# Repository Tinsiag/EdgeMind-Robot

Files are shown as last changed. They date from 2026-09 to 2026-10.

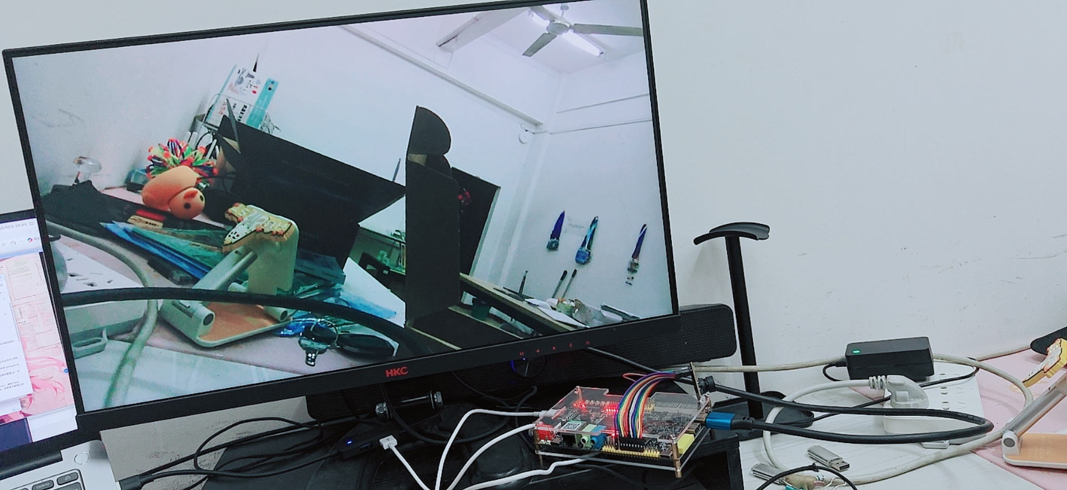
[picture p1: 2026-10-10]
code/fpga/acg720-ddr3/verification/verified-20261008/hardware-evidence/hdmi_scene.png

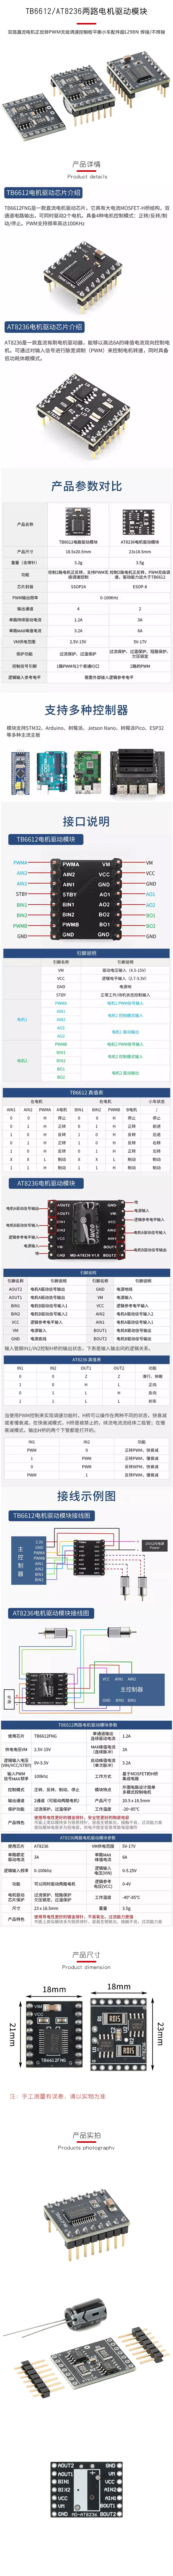
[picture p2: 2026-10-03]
doc/电机/合并长图_1-9.png

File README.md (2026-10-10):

# EdgeMind-Robot

基于 ACG720 FPGA 的双轮差速自主移动机器人项目。目标是先完成轮速闭环、传感器感知、视频链路与安全保护，再按需要扩展 Lichee Pi 4A 视觉计算。

## 文档与设计

- [项目功能需求书](doc/项目功能需求书.md)
- [系统设计文档](doc/文档.md)
- [电源预算与电源板架构初稿](doc/电源板/电源预算与架构初稿.md)
- [拟用电机资料核对](doc/电机/拟用电机资料核对.md)
- [FPGA 资料索引](doc/fpga/README.md)
- [代码目录](code/README.md)（含 ACG720 摄像头、DDR3 和电机工程入口与联调记录）
- [OV5640 与 DDR3 帧缓存排查及实现](code/fpga/acg720-ddr3/DDR3-FRAMEBUFFER-IMPLEMENTATION-2026-10-08.md)（800×480 静态、彩条、实景单帧链路通过）
- [DDR3 实景 HDMI 固件与验证资料](code/fpga/acg720-ddr3/verification/verified-20261008/README.md)（导入位流、实景显示反馈、照片与构建报告；完整时序尚未闭合）
- [机械参考图](model/README.md)（仅供版型与尺寸初查）
- [KiCad 电源板工程](pcb/power/)

当前电源预算和 KiCad 工程均为设计阶段内容，不代表电路已完成验证。板卡、电机、驱动、电池以及模块的供电范围和实际电流须按实物复核。

公开仓库收录项目文档、可编辑设计文件，以及 `model/` 下已有的两张机械参考图。WHEELTEC、ACG720 等厂家随附的原始 PDF、CAD 模型、安装包、视频与示例工程保留在本地；尤其 WHEELTEC 资料包的版权声明限制未经许可传播，故未上传这些原始附件。需要原始资料时请从厂家或购买渠道获取。

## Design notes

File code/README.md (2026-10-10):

# 代码目录

- [ACG720 / AT8236 电机控制](fpga/acg720-motor-test/README.md)：A712 启动和编码器活动、A713 左右持续启停已实测通过；当前 A717 为 50 kHz，占空比从 0% 到 100% 每 0.5 秒增加 5% 后循环，已下载，实物表现待反馈。S1/S2 独立启停，S0 停止，仅操作 SRAM。
- [电机启动排查与实现文档](fpga/acg720-motor-test/MOTOR-IMPLEMENTATION-2026-10-10.md)：接线、电源、三个 PWM 对照版本、通过证据及复现方法；尚未实现速度 PID 或与摄像头合并。
- [ACG720 GW5AT-60 DDR3 验证工程](fpga/acg720-ddr3/README.md)：原有 800×480 静态、彩条、实景单帧验证均通过。另已合入 [实景 HDMI 交付包](fpga/acg720-ddr3/verification/verified-20261008/README.md)，包含位流、实物反馈与完整验证资料；有图像显示反馈，时序尚未闭合，包内未提供完整 RTL。许可证已解决。
- [DDR3 帧缓存排查与实现文档](fpga/acg720-ddr3/DDR3-FRAMEBUFFER-IMPLEMENTATION-2026-10-08.md)：旧诊断缺陷、时钟与缓存实现、摄像头配置、仿真/实板证据、复现步骤和断电保存边界。

原厂配套源码、加密 IP 和位流保留在工程的 `.local/` 中，不直接并入公开仓库。我们编写的说明和构建入口纳入版本管理。

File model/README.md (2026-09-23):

# 机械参考图

本目录当前包含两张用户保存的板卡机械参考图，并非可编辑的 STEP/DWG 模型，也不能替代实物测量。

- `BE11300D28AD57C96EC11B6DEDBB3751.bmp`：灰度板卡布局图，图中标注外形约 84.45 mm × 99.06 mm；具体板型尚未核实。
- `EDE6B28DC4BC051CA18BC4B2684486C0.png`：Autodesk Viewer 的 `ACX720-V3.DWG.png` 截图，图中标注约 132.46 mm × 85.98 mm。

两张图的尺寸不同，不能把它们当成同一板卡的正反面或直接套用到 ACG720。开孔、接口和板框须对照实物及对应版本的正式机械图复核。原始设计文件的权利仍归相应提供方所有。

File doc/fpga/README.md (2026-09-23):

# FPGA 资料索引

本目录从 `/home/smallcoral/Dev/fpga/ACG720` 中筛选而来，只保留与 EdgeMind-Robot 当前方案直接相关的开发文档、硬件资料和机械模型。

**公开仓库说明：**本地目录保留原厂 PDF、表格和机械模型，GitHub 仓库仅收录我们撰写的 Markdown 索引与核对记录。下文指向原厂附件的相对路径需要在本地资料包中打开；若从 GitHub 克隆，需从厂家或购买渠道获取原始资料，不应将这些附件重新公开分发。

整理日期：2026-09-23。

## 目录说明

| 目录 | 内容 | 建议用途 |
| --- | --- | --- |
| `00_资料索引` | 原资料包的整理报告、章节导航、硬件与引脚核对、原始引脚表 | 开始开发前先读，了解资料冲突与已知问题 |
| `01_板卡硬件` | ACG720 主板原理图、通用引脚表、机械资料外链 | 接线、供电、IO Bank 电压和约束核对 |
| `02_官方开发手册` | Gowin 中文官方手册、Arora V 资源手册、Programmer 手册、PicoRV32 IP 配置说明 | 工具、约束、时序、GPIO、时钟、存储器、DSP 与软核开发 |
| `03_相关教程` | 从 70 章教程中筛出的 26 章 PDF | UART、状态机、IP、PWM、TFT/HDMI、I2C、DDR3、OV5640 |
| `04_机械模型` | ACX720 V2/V3 的 DWG、PcbDoc、STEP、STL、GLB、DXF、SVG 等参考模型 | 结构设计和安装空间预估；必须与 ACG720 实物复核 |
| `05_OV5640摄像头` | ACM5640-V5 用户指南、原理图、丝印、OV5640/SCCB/DVP 资料 | 摄像头接线、SCCB 初始化和 DVP 采集 |
| `06_显示屏` | 4.3/5 寸 TFT 背板、屏体、触控芯片和连接器资料 | 确认最终屏幕型号后选择性使用 |
| `07_关键器件数据` | 板载 DDR3、DVI、CH340、EEPROM、缓冲器手册 | DDR 视频缓存与板级接口排查 |
| `08_电机与驱动` | 现有 FPGA 双电机 PID 文档和 BTS7960/IBT-2 资料；拟用两种电机资料核对位于 `doc/电机/` | 核对驱动选型与现有控制实现 |

## 推荐阅读顺序

1. `00_资料索引/硬件与引脚核对.md`
2. `01_板卡硬件/ACG720_138K-60K通用原理图.pdf`
3. `01_板卡硬件/ACG720_138K-60K通用引脚分配.xlsx`
4. `02_官方开发手册/SUG100-4.4.6_Gowin云源软件用户指南.pdf`
5. `03_相关教程/02_Gowin基本开发流程.pdf`
6. 根据当前里程碑阅读 UART、PWM、I2C、DDR3、OV5640 或显示章节。

## 重要注意事项

- ACG720 资料同时涉及 GW5AT-138K 和 GW5AT-60K，工程器件、完整料号、引脚与配置手册必须按实物板卡选择。
- `04_机械模型` 的原始目录名为 `ACX720-V3机械文件`，不能直接认定其尺寸与 ACG720 完全一致；开孔、连接器位置和板框必须按实物或正式机械图复核。
- 原 ACG720 资料包没有独立的 MG513X/MG513XP28 电机数据手册，也没有 DRV8874 数据手册。现已在本地 `doc/电机/WHEELTEC 直流电机附送资料` 找到 WHEELTEC 的 MG513X 手册，可确认 1:28、12 V、0.36 A 额定、3.2 A 堵转等系列参数；实物编码器版本和实际电流仍需核对。两种拟用电机的铭牌与接线记录见 `doc/电机/拟用电机资料核对.md`。原厂手册不随公开仓库上传。
- `08_电机与驱动` 中的旧 PID 工程面向 TB6612；BTS7960/IBT-2 也是来源目录中的备选资料。当前项目计划优先评估 DRV8874，这些资料只能作为参考，不能替代最终驱动选型验证。
- 摄像头 V5 资料对自动对焦和补光能力存在版本描述冲突，应以手头模块实物、原理图和测试结果为准。
- 教程 PDF 中的示例参数、CST 和器件选择不一定都适用于当前板型，移植时应重新核对时钟、复位、IO 电压和时序约束。

## 未复制的内容

- `02_code` 示例工程与 RTL 源码
- `03_videos` 课程视频及随视频附带的工程输出
- `05_sofeware` 软件安装程序、工具运行文件和重复语言手册
- 仿真目录、综合/P&R 输出、位流、日志和版本管理残留
- 与机器人当前功能无直接关系的以太网、USB2.0、音频、红外、ADC/DAC 等整套教学资料

如需示例代码或某个未归档的器件手册，仍可从原始 ACG720 目录按需取用，不建议把整个资源包纳入本项目仓库。

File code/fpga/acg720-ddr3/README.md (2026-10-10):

# ACG720 GW5AT-60 DDR3 验证工程

本目录保存 ACG720 / GW5AT-60B 的 DDR3 调试工程。2026-10-08 本机已按官方第 38 章基线打通 OV5640 → 写 FIFO → DDR3 → 读 FIFO，800×480 RGB565 静态、彩条、实景整帧验证均通过。原有工程为实景单帧自检，只有 SRAM 配置，不断电保存；该阶段未验证连续 HDMI 显示。第 47 章 1280×720 主工程保留作历史。原厂依赖及本机构建产物保存在被 Git 忽略的 .local/ 下；原始资料包保持不变。

2026-10-10 另合入用户提供的 [DDR3 实景 HDMI 交付包](verification/verified-20261008/README.md)，完整保存 30 个原始文件，包含 `0x0000BC6C` 位流、HDMI 实景照片、用户反馈、构建/仿真及 PNR 报告。该包有实景显示功能反馈，完整时序仍有 101 个 setup、29 个 hold 违反端点；镜头移动后的刷新及长时间稳定性未单独确认，包内没有完整 RTL 源码。它与下述单帧自检工程和历史结果分开归档。

完整排查、实现与复现文档：[DDR3-FRAMEBUFFER-IMPLEMENTATION-2026-10-08.md](DDR3-FRAMEBUFFER-IMPLEMENTATION-2026-10-08.md)。

仓库也保存 [工程重建脚本](scripts/README.md)、`rtl/camera_init/` 中自编 SCCB 源码和 [实板验证快照](verification/README.md)。原厂依赖按脚本说明放入本机 `.local` 后，可重建本次三个工作工程。

历史交接记录：[DEBUG-HANDOFF-2026-10-06.md](DEBUG-HANDOFF-2026-10-06.md)。10 月 7 日已按用户要求继续，最新过程见 [DEBUG-SESSION-2026-10-07.md](DEBUG-SESSION-2026-10-07.md)。

2026-10-08 用户调整方向：先以官方第 38 章帧缓冲为基线，再向上接入 TY-OV5640。源码、硬件、电平和逻辑分析仪核对结果见 [FRAMEBUFFER-FIRST-PLAN-2026-10-08.md](FRAMEBUFFER-FIRST-PLAN-2026-10-08.md)。随后完成静态整帧验证，用户确认 `0x41A4` 的 D0～D5 亮、D6 灭、D7 闪：384000 像素 / 768000 字节经两端 FIFO 和 DDR 逐像素一致。详见 [FRAMEBUFFER-TEST-RESULT-2026-10-08.md](FRAMEBUFFER-TEST-RESULT-2026-10-08.md)。官方参考副本保持不变，摄像头彩条测试在独立工程继续。

2026-10-08 接线位置图及采集步骤见 [LOGIC-ANALYZER-WIRING-2026-10-08.md](LOGIC-ANALYZER-WIRING-2026-10-08.md)。P7 正面左下为 1 脚方形焊盘，外排偶数、内排奇数；模块 PWDN 在模块侧采集。本次仅整理接线图，没有编译、下载、实物接线或采集。

## 本机单帧验证历史状态（2026-10-08）

| 验证层级 | 已取得的证据 | 结论 |
| --- | --- | --- |
| 本机编译 | 主工程、固定模式 BIST、摄像头 DDR 诊断完成综合、布局布线和位流生成 | 已通过编译流程；尚未完整时序签核 |
| SRAM 下载 | Gowin USB Cable(FT2CH)，FPGA ID 0x0001481B，下载 100% 完成 | 下载成功；未写外部 Flash |
| DDR3 校准 | 10 月 8 日第 38 章整帧版 `0x41A4`，D0/D1/D2 亮 | 新帧缓存基线通过 |
| DDR3 静态整帧读回 | `0x41A4` D3/D4/D5 亮、D6 灭，48000 个读写命令，384000 个像素逐个比较 | 768000 字节链路通过；原 BIST 256 字节通过也保留 |
| 摄像头初始化 | 原主工程复核通过；被动观测版 D2/D4/D5 亮 | 初始化通过，DVP 像素及写 FIFO 输入已有活动 |
| 摄像头像素经 DDR 读回 | 彩条 `0x4FCF`、实景 `0xAF89` 均由用户确认 D0～D5 亮、D6 灭、D7 闪，完整帧 CRC 一致 | 摄像头完整帧链路通过；旧校准失败唯一触发未确定 |
| HDMI 图像 | 没有连接显示器 | 未验证 |

**2026-10-08 本机下载并验证了实景单帧版 `0xAF89`，用户确认 D0～D5 亮、D6 灭、D7 闪；彩条 `0x4FCF` 和静态 `0x41A4` 也已通过。三版均仅 SRAM 下载，外部配置 Flash 未写，断电会丢失配置。** 摄像头版位流、哈希、灯态定义、仿真和时序限制见 [CAMERA-FRAME-TEST-2026-10-08.md](CAMERA-FRAME-TEST-2026-10-08.md)。历史快照不表示当前板上配置；最近一次本机下载见 [电机工程 A717](../acg720-motor-test/README.md)。

- 已通过位流：.local/framebuffer-first/ch38-frame-test/impl/pnr/ch38_frame_test.fs
- SHA256：DD7959D0C266BD507D50DE8FBCF6DE9F9487E5F3B2076F643A168929D81A6222
- User Code / Status：0x000041A4 / 0x70026020
- 本版 D0～D5 均亮、D6 灭、D7 闪；含义与旧摄像头诊断不同，详见整帧验证记录。
- 前一观测版 0x7E20：用户确认 D1 灭，D0/D2/D3/D4/D5 亮。增加探针未解决校准。
- 仅 SRAM 下载，未写 Flash；断电会丢失本次配置。

已定位到源码连接缺陷：`pll_init_bypass=0` 使 DDR 的 mDRP 控制被屏蔽，适配器被综合删除。新帧缓存基线按原厂更新说明，在 PLL 锁定延迟后交出 mDRP 控制权，综合后适配器已保留，实板校准及静态整帧读回已通过。尚未单独做 A/B 测试，不能将旧诊断失败全部归因于这一处。原主工程和已通过 BIST 的位流及源码保持不变。

不能把该诊断版本的 D1 灭直接解释为 DDR 硬件故障。主工程与独立 BIST 曾通过校准，固定模式 BIST 也完成了真实写入/读回；失败诊断的根因仍待定位。

10 月 8 日进一步确认旧 FIFO 诊断存在写入数据量不足（2 个块却要求 8 个块才写）、未等实际写入完成就读、FWFT 比较晚一拍等缺陷；这些发生在校准之后，不能解释当时 D1 灭。证据及限制见 [LEGACY-DDR-DIAGNOSIS-2026-10-08.md](LEGACY-DDR-DIAGNOSIS-2026-10-08.md)。

## 本地工程与工具

| 文件 | 用途 |
| --- | --- |
| .local/framebuffer-first/ch38-frame-test/ch38_frame_test.gprj、build_ch38_frame_test.tcl | 已通过 800×480 静态整帧 DDR 读回 |
| .local/framebuffer-first/ch38-camera-bars/ch38_camera_bars.gprj、build_ch38_camera_bars.tcl | 沿用通过基线，接入 OV5640 彩条、整帧检查与 CRC |
| .local/framebuffer-first/ch38-camera-live/ch38_camera_live.gprj、build_ch38_camera_live.tcl | 关闭彩条，验证实景整帧，其他配置和缓存不变 |
| rtl/framebuffer_camera_test.v、rtl/camera_frame_gate.v | 摄像头完整帧选择、CRC32 和 DDR 命令计数验证 |
| .local/ch47/ov5640_ddr3_hdmi.gprj | 保留的第 47 章 1280×720 历史主工程 |
| build.tcl | 主工程编译入口 |
| .local/bist/ddr3_bist.gprj、build_bist.tcl | 已通过的固定模式 DDR3 BIST |
| .local/camera-ddr/camera_ddr_capture_bist.gprj | 尚未通过的摄像头原生 DDR 接口诊断 |
| .local/camera-ddr/camera_ddr_fifo_bist.gprj | 尚未通过的 F15 FIFO 诊断 |
| .local/camera-ddr/camera_ddr_fifo_bist_b21.gprj | 历史 B21 FIFO 诊断，未通过 |
| .local/main-observe/main_observe.gprj、build_main_observe.tcl | 保留主拓扑的八灯被动观测版，校准未通过 |
| .local/main-mdrp/main_mdrp.gprj、build_main_mdrp.tcl | mDRP 控制权修正版，10 月 7 日已下载，待灯态反馈 |
| rtl/ddr_readback_monitor.v、tests/ddr_readback_monitor_tb.v | 已通过模块仿真的被动读回比较器，尚未接入实板 |
| .local/logs/ | 历史记录与本次交接副本；旧记录须按各构建解释 |

实际成功使用的工具：

- C:/Gowin/Gowin_V1.9.12_x64/IDE/bin/gw_sh.exe
- C:/Gowin/Gowin_V1.9.12_x64/Programmer/bin/programmer_cli.exe

许可证问题已解除，成功编译是实际证据。原文中的 MAC/临时网卡/许可证失败描述属于历史排查，不是当前阻塞；不要重跑相关脚本，不需要教育版。最初提供的 V1.9.12.04_x64 路径在本轮未找到 gw_sh.exe，以以上可用工具为准。

项目器件为 GW5AT-LV60PG484AC1/I0、GW5AT-60B，B 版本。CST 原厂文件头的 138K 注释不能代替项目实际器件设置。下载器 USB location=546 为 10 月 7 日记录，后续操作前需要重新扫描。

## 已知通过的位流

- 已验证实景单帧：.local/framebuffer-first/ch38-camera-live/impl/pnr/ch38_camera_live.fs，User Code 0x0000AF89。
  SHA256：A718EFC364FEB9A6B47AD333686F0518D76A56DAD1955ABBA607262CAE790553
- 彩条和静态整帧：0x4FCF、0x41A4，分别保存在 `.local/framebuffer-first/ch38-camera-bars/`、`ch38-frame-test/`；哈希及证据见完整实现文档。
- 主工程：.local/ch47/impl/pnr/ov5640_ddr3_hdmi.fs，User Code 0x0000D80B。
  SHA256：D3CD6E1D3967B70441F22201E6A95FC143C7A99BDF63DE3F3B619E04EB23E09D
- 固定模式 BIST：.local/bist/impl/pnr/ddr3_bist.fs，User Code 0x00007CCF。
  SHA256：E3A7E06628D7E7600527DE1F8512C7F75EABC1F56067D59ECA29C410E99C5CBD
- 导入的 HDMI 实景交付：`verification/verified-20261008/firmware/ddr3_live_hdmi.fs`，文件头 User Code `0x0000BC6C`。
  SHA256：B6E3967AFC4785FF42CB147C1060A8A3D5E2AD39C560904A4F1E8B8B3D8FD6F8；实物反馈及未闭合时序见 [导入说明](verification/verified-20261008/README.md)。

位流身份/下载状态不表示 DDR 运行结果；校准和比较结果来自用户对相应 LED 的观察。10 月 7 日恢复原主工程后，D0～D3 全亮已再次由用户确认。

## LED 和复位

| 位流 | D0 / M22 | D1 / N22 | D2 / L21 | D3 / K21 |
| --- | --- | --- | --- | --- |
| 主工程 | DDR PLL 锁定 | DDR 校准完成 | 摄像头初始化完成 | camera/HDMI PLL 锁定 |
| 固定模式 BIST | DDR PLL 锁定 | DDR 校准完成 | 读回通过 | 测试失败 |
| 摄像头 DDR 诊断 | DDR PLL 锁定 | DDR 校准完成 | 初始化且捕获事件已接收 | 像素读回通过 |

灯高有效。固定模式 BIST 与摄像头诊断的 D3 含义相反；摄像头诊断 D2 灭不能单独判断 SCCB 失败。

原厂参考/BIST 使用 F15；主工程使用 B21（历史 cam 记录标为 S4），低有效。不要写成“S0/B21”。F15 和 B21 两个诊断版本都只亮 D0，不能确认复位引脚是根因。

## 当前摄像头映射

| 信号 | FPGA 球号 |
| --- | --- |
| RST / SCL / SDA | C14 / B13 / D15 |
| PCLK / HREF / VSYNC | B18 / D14 / C13 |
| D0..D7 | C15 / B15 / B16 / D17 / C17 / E16 / D16 / B17 |

已核对用户提供的 Downloads/cam。SCCB 为 100 kHz 开漏双向，主工程初始化完成包含读取 0x300A=0x56、0x300B=0x40。摄像头硬复位低约 1 ms，释放后约 20 ms 启动配置。

10 月 8 日用户确认模块是 18 针 TY-OV5640，并提供 T-OV5640-PCB-V1.0 针脚图。照片可见振荡器，但其频率未读清；新图纸未给频率，旧记录“25 MHz”尚未独立证实。工作副本不输出 FPGA XCLK，不约束未引出的 PWDN。模块端 PWDN 必须有可靠低电平；用户重新接线后主工程初始化通过，但未取得单独电气测量记录。旧 M20/B2/B1/J2/L18/A1 等映射只作为历史参考。

用户明确确认模块排针支持 3.3 V，后续按此接口规格。新机械图另标 DOVDD=1.8 V，尚无模块电平转换原理图解释该差异；不要把芯片供电标注直接等同于排针电平，也不自动改变 P6。当前 GPIO 映射对应 P7，具体针号和逻辑分析仪接法见 10 月 8 日方案。

## DDR 参数与后续未解决项

按现有资料/IP 配置：MT41K128M16JT-125:K，x16，256 MiB；400 MHz memory_clk，1:4，128-bit 用户接口，BL8，SSTL 1.5 V。用户逻辑使用 DDR IP 的 clk_out。旧主工程 DDR IP 的 clk 接 camera_pll 的 50 MHz 输出；新已通过基线接第 38 章系统 PLL 的 50 MHz 输出，DDR PLL 的 clkin/mdclk 接板载原始 50 MHz，摄像头 PCLK 仅用于采集/写 FIFO。

一帧 1280×720 RGB565 占 1,843,200 字节；新基线 800×480 占 768000 字节。原厂控制器读写地址范围相同，尚无独立多帧乒乓管理。10 月 8 日已通过一次静态整帧读回，但不代表全容量或长期稳定性验证。

10 月 7 日主工程 mDRP 修正版缺少独立灯态反馈。10 月 8 日已验证第 38 章静态整帧、摄像头内部彩条整帧和实景整帧。旧独立诊断的写入门槛、地址范围、一次性捕获事件等问题保留作历史证据，新的整帧验证流程已经绕开并处理这些缺陷；未改写旧诊断文件。

旧工程综合有重复声明、隐式网线、位宽和 mDRP 优化警告；新基线 mDRP 适配器已保留。新工程已增加 SDC，PCLK 在 PNR 中使用 PRIMARY；实景报告仍有 206 setup、56 hold 违反端点，CDC 和完整时序签核尚待完成。实板单帧通过不等于最终视频固件完成。

恢复命令和历史哈希见 10 月 6 日交接记录，新版哈希和日志见 10 月 7 日续调记录。原厂资料、外部 Flash 及无关 PCB 文件未改动。

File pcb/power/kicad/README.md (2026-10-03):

# 电源板 KiCad 工程

主工程：`ProPrj_power_2026-10-02.kicad_pro`。使用 KiCad 10 打开。

## 当前原理图（2026-10-03 第二版）

打开主工程后，进入同名主原理图 `ProPrj_power_2026-10-02.kicad_sch`，双击主页中的功能框进入对应子页。当前原理图为十页、211 个板上元件；PCB 已同步这版原理图的封装与网络，保留现有元件位置，布局布线尚未完成。

最新已修复网络名称：此前 `GND` 被翻译成“地”，现已恢复。全部实际网络使用 ASCII，原理图与 PCB 同步改名 51 个网络；122 个网络的完整连接分组保持一致，`GND` 对应 154 个有编号物理焊盘。实际网络名中没有问号。普通功能说明继续使用中文和默认字体，网络标签、电源符号值及层级引脚不参与中文化；普通说明不嵌入网络标识。这项约定见 [工程修改规范](AGENTS.md)。最新 ERC 与原理图/PCB 一致性检查均为 0 问题，说明见 [网络命名修复记录](review/网络命名修复说明.md)。

最近的保险丝修改在三个子页中：

- `01_power_input.kicad_sch`：F1 为“10A/32V MINI总保险”，采用集电通 `0297010.J / C55117678` 保险片；按后续绑定要求改为板载，连接顺序为 XT60 正极 → F1 → 防反接管。绑定 KiCad 自带 `Fuse:Fuseholder_Blade_Mini_Keystone_3568` 四孔保险座及其 3D 模型。
- `05_motor_left.kicad_sch`、`06_motor_right.kicad_sch`：F2、F3 已删除，原位置实线接通，电流采样与电子过流关断保留。

PCB 已恢复 F1 板载保险座，F2/F3 保持移除。209 个元件使用 KiCad 自带封装，2 个 AT8236 使用自建双排排母封装。保险片插入保险座上部两个夹口；四个 PCB 焊脚按 1/1、2/2 分成两个电气端，孔中心距为 9.92×3.40mm、钻孔 1.78mm。国产兼容保险座必须核对这套孔位。XT60 使用项目内的完整七实体模型。同步后原生 DRC 的原理图一致性问题为 0；当前仍无板框和走线，存在 499 项未连接及 25 项既有设计规则问题。详细核验和备份见 [PCB 同步说明](review/PCB同步说明_R2.md)。

主页九个功能框的整体布局未重排，保险丝采用通用原理图符号。查看这轮修改应进入上述子页；`review/schematic-backups/` 和 `review/connection-repair-trial/` 为历史副本。

最新说明见 [原理图修改说明](review/原理图修改说明_R2.md)，预览见 [十页原理图 PDF](review/电源板原理图_R2.pdf)，采购表见 [物料清单](review/电源板物料清单_R2.csv)。10A 是待启动电流与线束承载验证的初值，电池单节保护仍需确认。

## 早期审查记录

以下 53 个元件及其 PCB 同步记录针对早期导入工程，不代表当前第二版原理图的元件数量。

2026-10-02 按用户确认的外接双路 AT8236 模块方案完成原理图审查与封装同步。53 个物理元件、189 个引脚/焊盘已经对应；工程包含本地符号库、封装库及库表，可在其他安装了 KiCad 10 的机器上解析这些绑定。

当前仍有电源保护、模块线序/排距、3.3V 来源、物料冲突与 PCB 规则/断连问题，尚不具备投板条件。

2026-10-03 已补齐项目内 3D 模型，53 个元件及 23 个本地封装文件完成绑定；另有 4 个裸安装孔。
模型精度与核验见 [3D 封装绑定说明](review/3D封装绑定说明.md)，电感值和封装选择见 [L1/L2 选型核对](review/L1-L2电感选型核对.md)。

详细结论和已做修改见 [电源板审查与修改清单](review/电源板审查与修改清单.md)。原生 ERC/DRC、位号/引脚映射及验证记录在 `review/`。后续以这套 KiCad 工程为准修改；同级 EasyEDA 工程没有同步本次 KiCad 修复。

2026-10-03 重新导出当前原理图网表和 ERC，完成 [原理图功能可行性审查](review/原理图功能可行性审查_2026-10-03.md)，区分已有可用架构、影响功能的缺项及可选优化；本次审查未改电路。

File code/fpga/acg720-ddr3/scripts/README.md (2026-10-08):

# 重建 2026-10-08 通过的帧缓存工程

这些脚本保存本次对官方工程的实际改动方法，不包含原厂加密 IP、许可证、工具安装包或位流。运行只准备源码，不编译、下载，也不生成新的实板通过记录。

先把原厂第 38 章完整工程解压到 `.local/framebuffer-first/official-ch38/`，该目录应直接包含 `uart_ddr3_tft_hdmi.gprj` 和 `src/`。将官方第 47 章的下列依赖放在 `.local/ch47/src/` 对应位置。

- `rd_data_fifo/`、`wr_data_fifo/`，包含 `.v`、`.ipc` 和 `temp/FIFO/` 配置。
- `DVP_Capture/DVP_Capture.v`。
- `camera_init/ov5640_init_table_rgb.v`。

两套 FIFO 配置必须逐字节一致，脚本会检查，不能用不同宽度/深度的 FIFO 顶替。新增 SCCB 主机与初始化控制器在仓库 `rtl/camera_init/`，无需从忽略目录恢复这两份自编源码。

在 `code/fpga/acg720-ddr3` 目录，用 Python 3 的 UTF-8 模式依次运行。

```powershell
$python = 'C:/Users/sc/.cache/codex-runtimes/codex-primary-runtime/dependencies/python/python.exe'
& $python -X utf8 'scripts/prepare_frame_test.py'
if ($LASTEXITCODE -ne 0) { throw '静态工程准备失败' }
& $python -X utf8 'scripts/prepare_camera_test.py'
if ($LASTEXITCODE -ne 0) { throw '彩条工程准备失败' }
& $python -X utf8 'scripts/prepare_camera_live.py'
if ($LASTEXITCODE -ne 0) { throw '实景工程准备失败' }
```

这是本机已有的 Python 路径，其他机器应替换为实际 Python 3。脚本会重写对应工作副本源码；摄像头脚本还会生成 `rtl/framebuffer_camera_test.v`。已有通过的位流和源码应先单独保存。脚本不写原厂参考目录，不访问配置 Flash。

准备完成后，用 `build_ch38_frame_test.tcl`、`build_ch38_camera_bars.tcl`、`build_ch38_camera_live.tcl` 分别调用官方 Gowin 工具编译。源码重建在独立临时目录检查过，与本次通过工程的 src 文件逐字节一致，静态 277 文件、彩条和实景各 284 文件。重新编译后的位流仍须重新校验身份并上板测试，不将历史通过记录视为新构建结果。

`audit_camera_live.py` 检查本机彩条/实景源码差异、实景位流哈希及 PNR 时序端点。`verify_recorded_artifacts.py` 检查本机保留的三版位流、原下载日志、实板结果记录和说明文档；两者都需要相应 `.local` 文件，不是在线硬件测量。

历史实板结果也收录在 `verification/2026-10-08/`，便于不携带原厂依赖时查看证据。详细实现、SRAM 断电丢失和未完成的 HDMI/时序项见 [排查与实现文档](../DDR3-FRAMEBUFFER-IMPLEMENTATION-2026-10-08.md)。

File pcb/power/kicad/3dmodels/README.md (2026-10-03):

# 电源板 3D 模型

2026-10-03：模型文件随工程保存，通过 `${KIPRJMOD}/3dmodels/文件名.step` 引用。
PCB 的 53 个元件和本地封装库的 23 个封装均已绑定；H1～H4 是裸安装孔，不添加实体。
这些模型用于布局观察，不能直接作为厂家机械公差和装配验收依据。

| 使用位置 | 模型 | 匹配程度与变换 |
| --- | --- | --- |
| R1～R15 | R_0603_1608Metric.step | 通用 0603 外形 |
| 0603/0805 电容 | C_0603_1608Metric.step / C_0805_2012Metric.step | 通用尺寸；实际电容高度随具体料号变化 |
| LED1、D1 | LED_0603_1608Metric.step / D_SOD-123.step | 通用封装；LED 按焊盘中心微调位置 |
| U1/U5 | TSOT-23-8.step | 通用 TSOT-23-8，模型 Z 旋转 -90° 后匹配焊盘方向 |
| J1/J2 | PinHeader_1x08_P2.54mm_Vertical.step | 单排 8 针，2.54mm；X 偏移 -8.89mm、Z 旋转 -90° |
| J5～J8 | PinSocket_1x07_P2.54mm_Vertical.step | 单排 7 孔排母，2.54mm；X 偏移 -7.62mm、Z 旋转 -90° |
| J3/J4 | JST_XH_B6B-XH-A_1x06_P2.50mm_Vertical.step | XH 六针替代外形，焊盘实测间距 2.50mm；X 偏移 -6.25mm。不是汉夏厂家原始 CAD |
| USB1/USB2 | USB_C_Receptacle_GCT_USB4105-xx-A_16P_TopMnt_Horizontal.step | GCT 相近外形；模型 Y 偏移 -1.30mm 后，四个壳脚及信号脚位置与当前焊盘对应。不是 LAIL 原始 CAD |
| L1/L2 | L_TechFuse_SL0630.step | 0630 替代外形，7.12×6.60×3.00mm；PSA 规格为长最大 7.3mm、宽 6.6±0.2mm、高最大 3.0mm。模型不表示电感值或厂家标记 |
| SW2 | SS-12D10L5.step | McFLY 公开同型号模型，端子 X 为 -4.7/0/+4.7mm；沿用作者 X 旋转 -90°。不是厂家公差确认文件 |
| CN1 | XT60PW-M.step | 公开库中的完整 SolidWorks STEP，包含外壳、两组触点、焊接端子和固定片，共 7 个实体；外壳 18.2×15.5×8.4mm。偏移 (-12.35, 0, 4.2)mm、旋转 (-90, 0, 90)°，端子及固定片对齐现有焊盘 |

AT8236 模块目前仅显示板上的四条排母。模块实际孔排中心距、插接高度尚未确认，未虚构模块本体。
J6/J8 孔序方向问题仍需修改封装方向并重布线；增加模型不会解决该电气问题。

## 来源与许可

除开关和 XT60 外，STEP 文件来自本机 KiCad 10 官方模型库，保持原文件及作者头信息。
库许可为 CC-BY-SA 4.0，包含 KiCad 电子设计使用例外；见 [KiCad-LICENSE.md](KiCad-LICENSE.md) 和
[官方库许可](https://www.kicad.org/libraries/license/)。上表替代型号只是外形映射，没有更改 BOM 厂商型号。

开关来源：[McFLY 原始 STEP](https://gitea.mcflyer.ru/McFLY/kicad_libs/raw/commit/ce0ecbd4969c26cee32dae61125bddf5e67dff2c/my_additions.3d/ss-12d10l5.step)，
对应 [作者封装](https://gitea.mcflyer.ru/McFLY/kicad_libs/raw/commit/ce0ecbd4969c26cee32dae61125bddf5e67dff2c/my_additions.pretty/SS-12D10Lx_slider_switch.kicad_mod)。
检索到的来源未附独立许可证；保留作者归属，若单独公开分发该第三方模型，需要先确认许可。

XT60 来源：[Northeastern Rover Electrical Team 的 rover-lib 模型库](https://cadlab.io/project/25916/master/files/3dmodels/rover-lib.3dshapes)，文件 `XT60PW-M.step`。
保留下载文件原始内容，STEP 头记录 SolidWorks 2017、2019-02-01；来源未声明独立模型许可证，也未确认属于厂家原始 CAD。
简化外形已从活动模型目录移走，PCB 和封装库均使用上述完整模型。
绑定脚本、逐元件映射、核验记录在 `../review/`。

## 在 KiCad 中查看

请从本目录的上一级打开 `ProPrj_power_2026-10-02.kicad_pro`，再打开 PCB 并按 `Alt+3`。
如果旧 PCB 编辑窗口仍在打开，请先关闭旧窗口并重新打开更新后的 PCB；旧窗口内存中的模型引用可能会在保存时覆盖磁盘修复。
当前引用统一为 `${KIPRJMOD}/3dmodels/`，不再依赖原来缺失的 `EASYEDA_MODELS` 目录。

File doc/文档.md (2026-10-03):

## 器件选型总表

| 部分 | 方案 | 数量 | 用途与落实事项 |
| --- | --- | ---: | --- |
| 机械底盘 | 现有两驱动轮＋两万向轮 | 1 套 | 双轮差速；检查车架平整度，实测轮径和轮距 |
| FPGA | 小梅哥 ACG720 | 1 块 | RTL 实时感知控制、软核导航、视频显示；核对实物版本及例程 |
| 电机 | WHEELTEC MG513XP28_12V | 2 台 | 12 V 有刷减速编码电机；分别标定计数和方向 |
| 电机驱动 | 优先评估 DRV8874 单路模块 | 2 块 | 替换正式底盘中的 TB6612；采购前确认电流、散热、限流与 3.3 V 接口 |
| FPGA 摄像头 | OV5640 DVP 模块 | 1 个 | 选择与 ACG720 接口、排线和电平匹配的模块 |
| IMU | ICM-42688-P 模块 | 1 个 | 优先 SPI；姿态、角速度和相对航向融合 |
| 近距离避障 | VL53L1X 模块 | 3 个 | 左前、正前、右前；独立 XSHUT、共用 I²C |
| 碰撞检测 | 微动开关＋前保险杠 | 2 个开关＋1 套保险杠 | 左右触发，直接参与硬件安全逻辑 |
| 显示设备 | 与板卡官方视频例程匹配的屏幕或显示器 | 1 套 | 显示画面、姿态、速度、距离和故障；接口确认后定型号 |
| 电源 | 三串LiPo电池＋板载总保险＋分路稳压＋总开关＋急停 | 1 套 | 板载MINI总保险，位于XT60正极之后、防反接之前；单体电芯保护另行落实 |
| 调试工具 | USB 串口、万用表、限流电源、逻辑分析仪 | 1 套，可借用 | 电气检查、波形、日志和响应时间测量 |
| AI 扩展 | LicheePi 4A | 可选 1 块 | TH1520 NPU 视觉推理；模型需适配，实测性能，不按 TOPS 推断帧率 |
| AI 摄像头 | Linux UVC USB 摄像头 | 可选 1 个 | 接 LicheePi；第一版与 FPGA 摄像头分开使用 |
| LiDAR | LD06 | 可选 1 个 | 后期增强感知；接入雷达不等于完成 SLAM |

### 现有电机参数

| 参数 | 数值或描述 |
| --- | --- |
| 厂商与型号 | WHEELTEC，MG513XP28_12V / MG513X；标识 F01070199 的含义待核对 |
| 类型 | 直流有刷减速电机，全金属减速齿轮 |
| 额定电压／减速比 | 12 V／1:28 |
| 减速后空载／额定转速 | 370 ± 12 rpm／300 ± 12 rpm |
| 额定／堵转电流 | 0.36 A／3.2 A，每台 |
| 额定扭矩 | 1 kgf·cm，约 0.098 N·m |
| 堵转扭矩 | 4.5 kgf·cm，约 0.441 N·m |
| 标称功率／重量 | 4 W／约 0.17 kg |
| 输出轴径 | 约 6 mm |
| 编码器 | AB 相霍尔，基础分辨率 13 PPR，含义需核对 |
| 编码器供电 | 3.3～5 V，输出电平需单独确认 |
| 四倍频输出轴计数 | 若 13 PPR 为电机轴每相周期数，则理论 1456 counts/rev，必须实测 |

## 一、路线：FPGA 做实时闭环，软核做导航，AI 最后接入

| 评分项目 | 占比 | 开发重点 |
| --- | ---: | --- |
| FPGA 实时感知与控制 | 40% | 图像、姿态、编码器、闭环控制、实时避障 |
| 系统稳定性 | 25% | 供电、超时保护、异常停车、长时间运行 |
| 自主导航能力 | 20% | 相对定位、路径点、绕障后恢复导航 |
| 创新设计 | 10% | 并行采集、独立安全逻辑、可测量的确定性控制 |
| AI 扩展功能 | 5% | 目标识别、跟随与搜索 |

实施顺序：

**底盘与供电 → 电机闭环 → IMU/TOF → 摄像头显示 → 路径点导航 → 稳定性测试 → AI 扩展**

---

## 二、硬件问题

### 2.1 电机电源与 FPGA 电源分支供电

建议接法：

| 电源支路 | 连接方式 |
| --- | --- |
| 总输入 | 电池正极 → XT60 → 板载MINI总保险 → 防反接与总开关；单体电芯保护另行落实 |
| 执行器 | 急停与电子过流关断 → 动力总开关 → 电流采样 → 驱动 → 两台电机 |
| FPGA | 独立稳压模块 → ACG720 手册允许的输入 |
| AI | 独立 5 V 稳压模块 → LicheePi，容量按主板和 USB 外设峰值负载选择 |
| 传感器 | 对应电压的供电 → 摄像头、IMU、TOF，核查模块输入及 IO 电平 |

ACG720 输入为 6～12 V。普通三串锂电池满电为 12.6 V，在手册没有明确允许前，不直接接 FPGA 板输入。电机 12 V 额定值也不自动代表可以长期满占空比接满电电池，需核对许可范围。

注意：

- FPGA 稳压输出按板卡手册选定，例如在确认支持后选用 9 V；稳压器需覆盖整个电池放电范围。
- 电机回流不要经过 FPGA 或传感器地线。
- 各部分建立可靠公共参考地，优先星形布线。
- 驱动附近布置储能电容和去耦，电源方案要考虑电机回生。
- 急停使用适合直流负载的开关或切断装置，不让小按钮直接承受不匹配的大电流。
- **切断电机电源不等于立即刹住车**，断电滑行距离也要测试。
- 驱动使能引脚加硬件下拉，保证 FPGA 未配置、复位、下载程序时电机不动。

### 2.2 编码器分辨率必须实测

若“13 PPR”表示电机轴每相每转 13 个完整周期，减速比确为 28，那么四倍频后：

\[
N=13\times4\times28=1456\ \text{counts/输出轴转}
\]

**1456 只能作为待验证值。**

实际操作：

1. 电机断开驱动。
2. 给编码器正确供电。
3. 输出轴做好标记。
4. 手动转输出轴 10 圈。
5. 读取 FPGA 累计计数，除以 10。
6. 左右电机分别测量，并确认正转计数符号。

编码器电源为 3.3–5 V，不代表其输出一定可直接接 FPGA。需要核查输出形式、电平和上拉位置。

---

## 三、总体架构及职责分配

```mermaid
flowchart TD
    S["编码器、IMU、TOF、碰撞开关"] --> R["RTL 采集与时间戳"]
    R --> C["RTL 速度闭环与安全仲裁"]
    R --> N["软核：姿态、里程计、导航"]
    N --> C
    C --> M["驱动与双轮电机"]
    V["OV5640 DVP"] --> P["RTL 视频、DDR、OSD"]
    N --> P
    P --> D["显示设备"]
    A["可选 LicheePi：目标识别"] --> N
```

安全模块对最终驱动输出拥有禁止权限，普通速度斜坡不能延迟急停、碰撞或严重故障的响应。

### 分工原则

| 执行位置 | 负责功能 | 不负责 |
| --- | --- | --- |
| FPGA RTL | 编码器、PWM、轮速 PI、安全联锁、时间戳、视频流水线、通信外设 | 复杂传感器初始化和高层任务逻辑 |
| FPGA 软核 C  | IMU/ToF 驱动、姿态、里程计、导航和绕障 | 直接绕过安全模块操作电机 |
| Lichee Linux | 可选识别、任务请求、日志或可视化 | 安全停车、底层轮速闭环 |

软核优先使用**高云器件及工具版本匹配、已有可运行 BSP 的方案**。可优先评估 Gowin PicoRV32，但必须确认当前器件、工具和 BSP 的兼容性。先裸机定时任务，不必一开始移植 RTOS。软核位于 FPGA 内部，不需要额外增加 STM32。第一至第二周应跑通串口打印和外设寄存器访问。

建议软核代码、栈和实时数据优先使用片内存储，视频占用 DDR，避免显示带宽争用干扰控制；若必须共用 DDR，要测试最坏访问延迟。

---

## 四、FPGA 按这些模块拆分

### 4.1 时钟、总线及公共模块

| 模块文件 | 输入/输出 | 实现内容与验收 |
| --- | --- | --- |
| `clock_reset.v`  | 板载时钟 → 各时钟域/复位 | PLL 锁定后释放；各域复位同步释放 |
| `timebase.v` | 时钟 → µs 时间戳、周期 tick | 用计数使能产生周期，不随意生成新逻辑时钟 |
| `gpio_sync.v` | 外部单比特 → 同步信号 | 编码器、故障、开关信号同步 |
| `async_fifo.v` | 跨域数据流 | 使用成熟 FIFO IP，处理视频跨时钟 |
| `csr_bridge.v` | 软核总线 ↔ 外设寄存器 | MMIO 读写、地址译码、状态快照 |
| `event_logger.v` | 故障事件 → FIFO | 记录故障码和时间戳 |

多位数据跨域不能简单“每位串两个触发器”，要使用 FIFO、握手或稳定快照机制。

### 4.2 电机控制模块

| 模块文件 | 数量 | 具体功能 |
| --- | ---: | --- |
| `encoder_ab.v` | 2 | AB 四倍频解码、正反计数、非法跳变统计 |
| `speed_estimator.v` | 2 | 窗口计数测速，后续可加入周期测量 |
| `setpoint_ramp.v` | 2 | 限制目标轮速变化率 |
| `wheel_pi.v` | 2 | 定点 PI、输出饱和、积分抗饱和 |
| `motor_pwm.v` | 2 | 20 kHz PWM、占空比同步更新 |
| `motor_output.v` | 2 | 驱动接口适配、方向切换保护 |
| `safety_manager.v`  | 1 | 最高优先级停机、超时、故障锁存 |

### 编码器处理

解码合法序列，例如：

```text
00 → 01 → 11 → 10 → 00：+1
00 → 10 → 11 → 01 → 00：-1
00 → 11、01 → 10：非法跳变，计错误，不猜方向
```

安装后若某一侧前进计数为负，在参数中反号即可。

滤波时间应短于最高转速时的有效脉冲宽度，不能用按键那种毫秒级去抖处理编码器。

### 轮速估计

\[
v_{L,R}=\frac{\Delta n_{L,R}}{N_{L,R}}\frac{\pi D_{L,R}}{T_s}
\]

其中：

- \(D\)：有效轮径；
- \(N\)：每输出轴转计数；
- \(T_s\)：计数窗口；
- \(\Delta n\)：窗口增量。

建议初版：

- 公共调度 tick：1 kHz；
- 轮速估计和 PI：100 Hz，即 10 ms 更新；
- PWM：20 kHz。

**没有必要为了“实时”把轮速 PI 强行做到 1 kHz。**

例如轮径假设为 65 mm、编码器为 1456 counts/rev，在 0.1 m/s 时，1 ms 内只有约 0.71 个计数；直接用 1 ms 差分会明显抖动。低速性能不够时，再增加 M/T 测速，并设置无脉冲超时归零。

### 双轮 PI

\[
e_k=v_k^\*-v_k
\]

\[
I_k=\operatorname{clamp}(I_{k-1}+K_iT_se_k)
\]

\[
u_k=\operatorname{clamp}(K_pe_k+I_k+u_{ff})
\]

初版先不用微分项：

1. 悬空确认方向、编码器符号和反馈极性。
2. 关闭积分，逐步加比例。
3. 落地低速测试。
4. 增加积分，消除持续误差。
5. 最后补前馈、静摩擦补偿和斜坡。

定点实现先定义统一单位，例如轮速用带小数的 mm/s，乘法使用加宽中间结果；缩位前饱和，禁止溢出回绕。

目标反向时，先减速至接近零，再切换方向。真正的紧急停机应绕过普通斜坡；刹车还是关断按驱动能力及测试结果配置。

### 4.3 安全模块：必须独立于导航软件

建议状态：

| 状态 | 含义与转换 |
| --- | --- |
| `DISARMED` | 未解锁，禁止运动；自检完成后可进入 READY |
| `READY` | 等待明确解锁和有效任务，满足条件后进入 RUN |
| `RUN` | 执行任务；停止后退出运行，故障时进入 FAULT |
| `FAULT` | 停止并锁存故障，清除后回到 DISARMED |

允许进入 `RUN` 的条件：

- 急停释放；
- 驱动无故障；
- 软核心跳有效；
- 当前控制命令未过期；
- 对当前动作必需的传感器有效；
- 用户显式解锁。

建议故障表：

| 事件 | 动作 |
| --- | --- |
| 急停触发 | 硬件切断执行器支路，同时记录状态 |
| 碰撞触发 | 立即进入停止动作并锁存 |
| 驱动过流/过温 | 禁止输出，锁存故障 |
| 软核心跳超时 | 停机 |
| 当前控制源命令过期 | 停机或受控停止 |
| 前向 ToF 失效 | 禁止继续依赖该感知前进，基础版直接停机 |
| 编码器异常 | 停止对应控制，禁止长期大占空比输出 |

碰撞输入可以“触发即锁存、释放再去抖”，不应为了等待几十毫秒稳定而推迟首次停止。

**解除故障不等于自动恢复运行**：清故障、重新解锁、重新下发任务应是三个明确动作。

---

## 五、传感器按“RTL 总线 + 软核驱动”实现

### 5.1 ICM-42688-P：优先 SPI

### RTL

`spi_master.v`：

- 支持所需 SPI 模式；
- 可配置分频；
- 多字节连续读写；
- TX/RX FIFO；
- 完成和超时状态；
- 数据就绪信号同步与时间戳。

### 软核

`icm42688.c`：

1. 读器件标识；
2. 复位并等待；
3. 配置量程、输出频率和滤波；
4. 静止采样，估计陀螺零偏；
5. 按数据就绪事件读取；
6. 转换单位并做安装坐标系变换；
7. 输出有效标志和采样时间。

建议起始设置：

- IMU 采样：约 200 Hz；
- 姿态融合：约 200 Hz；
- 屏幕姿态数值刷新：10–20 Hz。

具体寄存器值以器件手册和模块接法为准。

### 姿态算法

第一版用互补滤波即可：

\[
roll_k=\alpha(roll_{k-1}+\omega_x\Delta t)
 +(1-\alpha)roll_{acc}
\]

pitch 同理。大加减速时，加速度计不再只测重力，应降低其校正权重。

航向使用陀螺和轮式里程计融合：

\[
\Delta\theta_{enc}=\frac{\Delta s_R-\Delta s_L}{b}
\]

\[
\Delta\theta=
\beta(\omega_z-b_z)\Delta t+
(1-\beta)\Delta\theta_{enc}
\]

需要明确：

> ICM-42688-P 是六轴 IMU，无法给出长期无漂移的绝对航向；编码器与陀螺融合也不能消除所有航向漂移。

第一版展示的是相对初始姿态的 yaw，而不是绝对北向角。

### 5.2 三个 VL53L1X：独立 XSHUT，共用 I²C

建议安装：

- 中间：正前方；
- 左侧：左前方初始约 30°；
- 右侧：右前方初始约 30°。

最终角度由车体宽度和测试场地确定。三束测距并不覆盖完整车体轮廓，原地旋转时车角的扫掠区域尤其要注意。

### RTL

`i2c_master.v`：

- 开漏输出；
- START/STOP；
- ACK/NACK；
- 连续寄存器访问；
- 超时；
- 条件允许时的总线恢复。

`tof_guard.v`：

- 三路距离、状态、时间戳寄存器；
- 数据过期判定；
- 按速度档位检查保守距离阈值；
- 输出危险/失效标志给安全模块。

### 软核

`vl53l1x_port.c` 适配厂商驱动需要的 I²C 读写和延时接口，不建议手写整个传感器初始化 RTL。

三颗上电默认地址相同，通常采用：

```text
全部 XSHUT 拉低
    ↓
释放左探头 → 等待启动 → 改地址
    ↓
释放中探头 → 等待启动 → 改地址
    ↓
释放右探头 → 等待启动 → 改地址
    ↓
配置测量 → 周期读取
```

可在自己的 I²C 控制器中统一使用 7-bit 地址，例如 `0x30/0x31/0x32`；适配厂商 API 时明确其是否要求左移后的地址，避免默认地址 `0x29` 与 `0x52` 混淆。

同时核查模块的 I²C 上拉电压和 XSHUT 电平，不能把转接板与裸芯片的耐压混为一谈。

**调度建议：**

- 先逐个探头调通；
- 再接三颗；
- 测试同时测量是否存在光学干扰；
- 若采用错峰/串行测量，重新统计每个方向的真实刷新间隔。

导航循环跑 50 Hz，不代表 ToF 就提供 50 Hz 的新测量。

---

## 六、摄像头与显示链路：先通图，再叠加

### 6.1 模块拆分

| 模块 | 功能 |
| --- | --- |
| `ov5640_init.c` 或初始化 ROM | 摄像头 SCCB 配置 |
| `cam_xclk.v` | 按模块要求提供摄像头时钟 |
| `dvp_rx.v` | 在 PCLK 域采集 VSYNC/HREF/DATA |
| `pixel_unpack.v` | 两字节组装 RGB565 像素 |
| `video_async_fifo.v` | PCLK 域到 DDR 接口域 |
| `frame_writer.v` | 按帧/行写入 DDR |
| `frame_manager.v` | 帧完成握手、读写缓冲所有权 |
| `frame_reader.v` | 从 DDR 读取显示像素 |
| `display_timing.v` | 按实际接口生成显示时序 |
| `osd_overlay.v` | 字符、数值、状态框叠加 |

第一版建议从官方例程支持的低分辨率开始，例如 **640×480、RGB565、约 30 fps**。

其摄像头有效像素写入量约为：

\[
640\times480\times2\times30
=18.4\ \text{MB/s}
\]

双帧缓存约需 1.23 MB。显示若以 60 Hz 读取，读流量还要另算，并预留 DDR 效率和突发访问裕量。

帧缓存必须有读写所有权管理；写端不能覆盖显示正在读取的帧。不同帧率下允许丢帧或重复帧，不能靠无条件交换地址碰运气。

### 6.2 屏幕内容

建议显示：

```text
OV5640 实时画面

MODE: AUTO       WP: 2/4
ROLL:  +1.2°     PITCH: -0.8°
YAW:  +35.6°
VL: 0.18 m/s     VR: 0.20 m/s
TOF: 620 / 810 / 540 mm
FAULT: NONE
```

软核每 50–100 ms 更新一次 OSD 参数，RTL 负责逐像素叠加；姿态寄存器使用一致性快照，避免显示到更新一半的数据。

**实施次序：**

1. 显示彩条；
2. 摄像头数据计数正确；
3. 显示摄像头画面；
4. 加固定文字；
5. 加姿态数值；
6. 加速度、距离和故障状态。

不要把视频首次调通与整车闭环首次调通安排在同一个步骤里。

---

## 七、导航：先完成“已知起点、小场地、短路径”

### 7.1 第一版的工作边界

建议演示场景：

- 平整室内地面；
- 已知起点和初始朝向；
- 3–5 个预设路径点；
- 少量静态、规则、具有足够测距反射的障碍物；
- 保留足够宽的绕行空间；
- 初始速度限制在 0.15–0.25 m/s。

这版是**相对定位的路径点导航**，不是任意环境 SLAM。

### 7.2 里程计

\[
\Delta s_L=\frac{\Delta n_L}{N_L}\pi D_L,\quad
\Delta s_R=\frac{\Delta n_R}{N_R}\pi D_R
\]

\[
\Delta s=\frac{\Delta s_R+\Delta s_L}{2}
\]

结合前述融合航向增量：

\[
x_{k+1}=x_k+\Delta s\cos(\theta_k+\Delta\theta/2)
\]

\[
y_{k+1}=y_k+\Delta s\sin(\theta_k+\Delta\theta/2)
\]

\[
\theta_{k+1}=\operatorname{wrap}(\theta_k+\Delta\theta)
\]

轮径和轮距要标定：

- 多次直行已知距离，标定左右有效轮径；
- 多次低速定点转向，修正有效轮距；
- 正反方向重复，观察万向轮和打滑造成的不一致。

两只万向轮要安装平整、转动顺畅。车架不平会改变驱动轮受力，引起里程误差。

### 7.3 路径点控制

当前目标点 \((x_g,y_g)\)：

\[
\rho=\sqrt{(x_g-x)^2+(y_g-y)^2}
\]

\[
e_\theta=\operatorname{wrap}(\operatorname{atan2}(y_g-y,x_g-x)-\theta)
\]

第一版采用“先转向，再前进”：

- 角度误差大于约 25°：低速原地转向；
- 角度基本对准：边走边修正；
- 接近目标点：减速；
- 进入到达半径并满足稳定条件：切换下一个点。

控制请求：

\[
v=\operatorname{clamp}(k_\rho\rho,0,v_{max})
\]

\[
\omega=\operatorname{clamp}(k_\theta e_\theta,-\omega_{max},\omega_{max})
\]

差速变换：

\[
v_L^\*=v-\frac{b\omega}{2},\quad
v_R^\*=v+\frac{b\omega}{2}
\]

若任一轮超限，两轮按相同比例缩小，尽量保持请求曲率。

软核只向控制模块提交 \(v,\omega\) 或轮速目标，不直接写 PWM。

---

## 八、自主绕障不能只写“遇障停车”

建议实现一个有恢复条件、有超时的状态机：

正常流程为：路径点跟踪 → 减速 → 选择方向 → 转离障碍 → 绕行 → 恢复导航。任何状态出现碰撞、感知失效或超时，均进入安全停止。具体条件见下表。

### 各状态的动作

| 状态 | 动作 | 退出条件 |
| --- | --- | --- |
| `FOLLOW_WAYPOINT` | 正常导航 | 进入减速区 |
| `DECELERATE` | 受控减速 | 接近停止或安全低速 |
| `CHOOSE_SIDE` | 比较左右有效距离和车体裕量 | 有可尝试方向，否则停机 |
| `TURN_AWAY` | 小角度、低速转向 | 达到角度且前方可走 |
| `PASS_OBSTACLE` | 沿选定侧绕行 | 已行驶一定距离，障碍趋势支持通过判断 |
| `REJOIN_PATH` | 重新朝原目标导航 | 恢复正常路线 |
| `SAFE_STOP` | 停止并报告原因 | 人工确认/重新规划 |

实现时增加：

- 距离阈值迟滞；
- 连续有效样本确认；
- 单状态超时；
- 最大绕行距离；
- 最大尝试次数；
- “距目标长期不减小”的无进展检测。

三束 ToF 无法证明整个绕行空间无障碍。基础版只承诺在已定义的简单障碍场景内完成绕障；U 型障碍、窄缝和复杂动态障碍可能需要停机，而不是不断盲试。

### 安全距离必须随速度变化

建议使用：

\[
d_{stop}=vT_{latency}+\frac{v^2}{2a_{brake}}+d_{margin}
\]

其中 `T_latency` 包括：

- 最坏测量等待；
- 传感器内部测量；
- 总线读取和软件处理；
- 命令更新；
- 驱动及机械响应。

例如仅作为计算示例：

- \(v=0.25\ \text{m/s}\)
- \(T_{latency}=0.10\ \text{s}\)
- \(a_{brake}=0.5\ \text{m/s}^2\)
- \(d_{margin}=0.10\ \text{m}\)

则：

\[
d_{stop}\approx0.188\ \text{m}
\]

最终阈值要使用实测的最坏延迟、最小制动减速度，并补偿传感器相对保险杠的安装偏移。

**不要把 FPGA 联锁微秒级响应宣传为机器人从看见障碍到停住只需微秒。**

### 后方没有传感器的处理

- 自主绕障第一版不采用长距离倒车；
- 后退基础动作在受控空旷场地低速演示；
- 若要自主倒车，优先增加后向测距；
- 原地旋转也要考虑侧后方扫掠范围。

---

## 九、软核软件、寄存器和通信怎么组织

### 9.1 裸机任务表

| 周期/触发 | 任务 |
| --- | --- |
| 1 ms 基准 tick | 更新时间、置任务标志 |
| IMU 数据就绪，约 200 Hz | 读取 IMU、姿态与航向更新 |
| 10 ms | 原子读取编码器快照、更新里程计 |
| 20–50 ms | 执行导航与绕障，提交新命令 |
| 传感器数据就绪 | 读取 ToF、检查状态并提交安全寄存器 |
| 50–100 ms | 更新 OSD 和遥测 |
| 持续 | UART 帧解析、非阻塞外设状态机 |

中断只置标志或收发少量数据，不在中断中等待整次 ToF 测量完成。

看门狗应在关键任务都按时完成后喂狗，不要让一个仍在运行的定时中断掩盖主循环卡死。

### 9.2 建议寄存器窗口

以下是**自定义设计示例，不是板卡现成地址**：

| 偏移 | 内容 |
| --- | --- |
| `0x0000` | 版本、运行模式、使能、故障、心跳 |
| `0x0100` | 左右编码器计数、快照、非法跳变计数 |
| `0x0200` | 轮速目标、实测轮速、PI 参数、PWM 状态 |
| `0x0300` | ToF 距离、有效标志、时间戳、阈值 |
| `0x0400` | SPI 控制/FIFO |
| `0x0500` | I²C 控制/FIFO、XSHUT 控制 |
| `0x0600` | UART 控制/FIFO |
| `0x0700` | OSD 参数 |
| `0x0800` | 事件 FIFO、统计计数 |

左右轮目标和命令有效期使用影子寄存器，最后写 `CMD_COMMIT` 原子生效，避免左轮已更新、右轮还没更新的中间状态。

### 9.3 UART 协议

推荐：

```text
SYNC | VERSION | TYPE | LENGTH | SEQ | TTL_MS | PAYLOAD | CRC16
```

命令类型：

- 解锁/停止；
- 手动速度；
- 路径任务；
- AI 目标信息；
- 状态查询；
- 参数设置。

要求：

- CRC 错误直接丢弃；
- 检查长度上限、参数范围和序号；
- 命令寿命由 FPGA 本地接收时间计算；
- 未做时钟同步时，不用 Linux 时间戳直接判断 FPGA 超时；
- 禁止失联后一直执行上一条运动命令。

优先级应为：

```text
硬件急停
  > 故障/碰撞联锁
  > 安全限制
  > 当前已授权控制模式
```

手动、路径导航、AI 跟随是互斥控制模式，不应多个来源同时争夺轮速。

---

## 十、Lichee Pi 4A：AI 扩展

Lichee Pi 4A 的 TH1520 标称带 4 TOPS INT8 NPU，但这不代表任意模型都能直接运行，也不能仅凭 TOPS 推断实际检测帧率。[Sipeed LicheePi 4A NPU 使用文档](https://wiki.sipeed.com/hardware/zh/lichee/th1520/lpi4a/6_peripheral.html)

建议只选择：

> **指定目标识别 → 发送目标方位 → FPGA 控制靠近 → ToF 保持距离 → 目标丢失停车。**

接法：

```text
UVC摄像头 → Lichee Pi 4A → UART → FPGA
OV5640    → FPGA视频链路 → 显示
```

UART 只发：

```text
目标类别、置信度、图像中心偏差、框大小、序号、有效期
```

不传原始视频。

实施步骤：

1. Linux 下稳定读取 UVC 图像；
2. CPU 上跑通一个小模型；
3. 核实 NPU SDK、模型转换和算子支持；
4. 做 INT8 量化；
5. 实测帧率和端到端延迟；
6. 接入 FPGA 的 AI 模式；
7. 测试目标丢失、遮挡、串口断开时停车。

需要注意：前方 ToF 测到的物体不一定是识别框中的目标。第一版只在目标居中、视线简单、无其他近障碍时做低速靠近，测距主要作为保守安全约束。

**LD06 暂不接入主线。**基础版稳定后，再评估雷达里程计/建图。若扩展导航运行于 Linux，仍应由 FPGA 保留速度闭环与独立安全链路，并确认符合赛道要求。

---

## 十一、工程目录建议

项目根目录建议为 `robot_fpga/`：

| 目录 | 内容 |
| --- | --- |
| `docs/` | 接线供电、寄存器表、UART 协议、测试计划 |
| `rtl/top/`、`rtl/common/` | 顶层、时钟、复位、时间戳、跨时钟域处理 |
| `rtl/motor/`、`rtl/safety/` | 编码器、测速、PI、PWM、安全联锁和故障日志 |
| `rtl/peripheral/`、`rtl/bus/` | SPI、I²C、UART、软核外设总线 |
| `rtl/video/` | DVP、帧缓存、显示、OSD |
| `firmware/bsp/`、`firmware/drivers/` | 板级支持、IMU/TOF/摄像头驱动 |
| `firmware/control/` | 姿态、里程计、差速变换 |
| `firmware/navigation/`、`firmware/app/` | 路径点、绕障、任务调度 |
| `sim/` | 编码器、PI、安全、UART、帧缓存管理仿真 |
| `constraints/` | 引脚、电平、时钟、时序约束 |
| `tools/` | 串口调参、日志、曲线分析 |
| `linux_ai/` | 可选 Linux 视觉扩展 |

每个模块都交付四项：**接口说明、可运行实现、测试方法、测试记录**。不要只留一份“综合成功”的代码。

---

## 十二、按 10 周拆实施里程碑

这是相对开发周期，不代表赛事实际截止日期；工期不足时先删 AI 和雷达，不删基础安全测试。

| 阶段 | 任务 | 必须通过的验收 |
| --- | --- | --- |
| 第 1 周  | 原理图核对、驱动替换、电源、急停、FPGA 基础工程 | 下载/复位不转轮，电压正常，急停有效 |
| 第 2 周  | 单轮编码器、PWM、符号验证、计数标定 | 正反转计数正确，无异常跳变 |
| 第 3 周  | 双轮 PI、斜坡、通信、故障联锁 | 前后左右、定点转向，拔通信线可停 |
| 第 4 周  | IMU 与三 ToF、传感器异常处理 | 稳定采样，掉线可检出并停机 |
| 第 5 周  | 视频采集显示、OSD | 实时画面和姿态同屏稳定运行 |
| 第 6 周  | 轮径轮距标定、里程计、路径点 | 无障碍完成多点路线 |
| 第 7 周  | 减速停车、绕障 FSM、恢复路径 | 简单障碍绕行后继续到终点 |
| 第 8 周  | 满载、电源扰动、长期运行、故障注入 | 连续运行不失控、不复位 |
| 第 9 周  | AI 目标识别/靠近，可选 | AI 失联不影响基础安全 |
| 第 10 周 | 固化参数、复测、报告和视频 | 演示流程可重复，证据齐全 |

第一周统一寄存器、单位、坐标系、通信协议，否则集成成本会很高。

---

## 十三、验收指标和答辩证据

以下是建议的**设计目标**，不是现有器件已经达到的性能：

| 项目 | 起始目标 |
| --- | --- |
| 轮速闭环 | 在明确的非低速测试区间，稳态误差争取 ≤5% |
| 直线运行 | 2 m 路段横向偏差争取 ≤10 cm |
| 定点转向 | 90° 转向误差争取 ≤5° |
| 路径点 | 受控小场地到达半径先设 15 cm，稳定后尝试 10 cm |
| 绕障 | 固定简单场景连续 10 次，争取成功 ≥9 次 |
| 视频 | 目标配置下连续运行 30 min 无明显撕裂/卡死 |
| 稳定性 | 整车连续运行 30 min 无意外复位或失控 |
| 安全 | 急停、碰撞、命令超时、关键传感器失效均有实测记录 |

必须留下的证据：

1. **轮速阶跃曲线**：目标、实测、PWM、电池电压。
2. **制动距离曲线**：不同速度、载荷、电量和地面。
3. **路径重复实验**：每次起点、终点误差、成功条件。
4. **故障注入视频**：拔串口、断传感器、软核卡死、按急停。
5. **时序与资源报告**：尤其 DVP、DDR、显示跨域和约束完整性。
6. **安全响应分段测量**：输入到 PWM 禁止的逻辑延迟，与车辆停住时间分别报告。

不要通过无保护长时间堵转来验证驱动，应使用受控限流和安全负载测试。

---

## 十四、参赛展示顺序

一段演示完成以下闭环：

1. 上电，电机默认禁用，屏幕显示图像和姿态。
2. 解锁，展示前进、后退、转向和定点旋转。
3. 选择路径任务，依次经过预设路径点。
4. 遇到障碍自动减速、判断方向、绕行并恢复导航。
5. 到终点停车，显示完成状态。
6. 拔掉通信或触发故障，证明系统能安全停止。
7. 时间允许，再展示指定目标识别与低速靠近。

项目展示重点：视频、传感器和控制并行工作；运动链路具有明确周期和独立联锁；用测试数据证明性能。

## 十五、统一接口、调试初值与压缩计划

### 15.1 公共数据约定

| 数据 | 统一约定 |
| --- | --- |
| 编码器 | 有符号累计计数；两侧向前均为正，明确计数回绕处理 |
| 轮速 | 有符号 mm/s；定点小数位由接口文档统一 |
| 距离 | mm＋有效标志＋采样时间；换算为车体净空 |
| 位置／角度 | 内部统一 m、rad，寄存器可用 mm、mrad；转换集中处理 |
| 时间戳 | FPGA 本地微秒计数，明确位宽和回绕比较规则 |
| 控制命令 | 模式、左右目标、序号、有效期限、原子提交位 |
| 故障 | 位图、首次发生时间、清除条件 |

IMU、编码器融合应按时间戳对齐，避免重复积分或把不同时段的增量直接相加。AI 命令 TTL 从接收时开始只能防止通信失联，不能证明图像新鲜；还需约束采集到发送的处理延迟、发送端丢弃积压帧，或建立两端时钟关系。

### 15.2 统一调试初值

| 项目 | 合并后的初始方案 |
| --- | --- |
| 主时钟 | 沿用板卡例程，若实物板载为 50 MHz 则以此起步，不预设未确认频率 |
| 公共 tick／速度环／PWM | 1 kHz／100 Hz／20 kHz，驱动支持后使用 |
| IMU | 约 200 Hz，按数据就绪和真实时间间隔处理 |
| TOF | 每路约 20～30 Hz 为目标，按测量预算、调度和干扰测试确认 |
| 导航 | 20～50 Hz |
| OSD／日志 | 10～20 Hz |
| 视频 | 例程支持时选 640×480、RGB565、30 fps |
| 自主速度 | 0.15～0.25 m/s |
| 路径点容差 | 先 0.15 m，稳定后尝试 0.10 m；用外部实际测量验收 |
| 距离阈值 | 低速调试可从停止 0.20 m、减速 0.50 m 试起，必须按实测制动净空修订 |
| 软核心跳 | 可从 200 ms 超时试起，按实际调度和停车距离确定 |

视频单帧为 614,400 字节，双帧为 1,228,800 字节，约 1.23 MB；30 fps 写入约 18.4 MB/s。若显示以 60 Hz 读出同尺寸帧，有效读取约 36.9 MB/s，合计约 55.3 MB/s，尚未计入 DDR 访问效率和额外开销。

### 15.3 示例路径与 AI 任务

| 路径点 | X（m） | Y（m） | 动作 |
| --- | ---: | ---: | --- |
| 起点 | 0 | 0 | 固定起始朝向，清零里程计 |
| P1 | 1 | 0 | 前进到达 |
| P2 | 1 | 1 | 转向并到达 |
| P3 | 2 | 1 | 放置简单障碍，绕行后继续 |
| 终点 | 2 | 2 | 停车并显示完成 |

AI 扩展按“静态图片检测 → 视频检测与延迟测量 → 串口结果 → 目标对准 → 低速靠近”推进。可选“红色水瓶搜索”：瓶子检测＋框内颜色判断＋多帧确认，随后搜索、对准、靠近和停车。前向 TOF 始终作为安全约束，不无条件充当目标瓶子的距离。

## 十六、开工前待确认清单

- [ ] ACG720 实物 FPGA 型号、板卡版本、原理图、IO Bank 电压、供电范围。
- [ ] 与板卡匹配的 OV5640、DDR、显示和软核例程及引脚约束。
- [ ] 替代驱动模块的型号、持续电流、散热、限流、电流反馈和故障接口。
- [ ] 电池串数、容量、满电电压、放电能力、充电器与分路稳压方案。
- [ ] 左右有效轮径、有效轮距、车体轮廓、传感器相对保险杠的位置。
- [ ] 两台电机实测每圈计数、编码器输出电平、正反方向。
- [ ] IMU 安装轴向、三路 TOF 的 XSHUT 和上拉电压。
- [ ] 统一单位、坐标系、寄存器、UART 协议和验收场地。

首个里程碑：确认驱动与供电后，完成“单轮编码器反馈＋PI 调速”，同时验证软核最小工程和视频官方例程。

## 十七、资料入口

以下为前文建议引用或所涉器件的官方资料入口，便于后续核对；本次任务以内容合并为主，未新增网页核验。

- [东芝 TB6612FNG 数据手册](https://toshiba.semicon-storage.com/info/TB6612FNG_datasheet_en_20141001.pdf?did=10660&prodName=TB6612FNG)
- [TI DRV8874 产品资料](https://www.ti.com/product/DRV8874)
- [Gowin PicoRV32 官方介绍](https://www.gowinsemi.com/en/support/ip_detail/46/)
- [TDK ICM-42688-P 数据手册](https://product.tdk.com/system/files/dam/doc/product/sensor/mortion-inertial/imu/data_sheet/ds-000347-icm-42688-p-v1.6.pdf)
- [ST VL53L1X 数据手册](https://www.st.com/resource/en/datasheet/vl53l1x.pdf)
- [ST VL53L1X ULD 驱动](https://www.st.com/en/embedded-software/stsw-img009.html)
- [Sipeed LicheePi 4A NPU 使用文档](https://wiki.sipeed.com/hardware/zh/lichee/th1520/lpi4a/6_peripheral.html)

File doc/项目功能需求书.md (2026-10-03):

# 基于 ACG720 FPGA 的自主移动机器人功能需求书

| 项目 | 内容 |
| --- | --- |
| 文档版本 | V1.0 |
| 文档状态 | 需求草案，部分硬件参数与验收条件待确认 |
| 项目平台 | ACG720 FPGA 开发板、双轮差速底盘 |
| 基础版本 | 运动控制、传感器感知、视频显示、路径点导航、简单绕障与安全保护 |
| 可选扩展 | 基于 LicheePi 4A 的目标识别与低速靠近；后续评估 LiDAR |
| 文档用途 | 明确开发范围、功能行为、接口约束、验收标准与交付要求 |

## 一、项目概述

### 1.1 项目背景

本项目基于现有双轮差速底盘和 ACG720 FPGA 开发板，开发一套可在受控室内场地运行的自主移动机器人，用于工程实践及项目展示。

系统利用 FPGA 实现实时采集、轮速闭环、安全联锁和视频处理，由 FPGA 内部软核处理器完成传感器驱动、姿态与里程计计算、路径点导航和绕障决策。基础功能稳定后，可增加外部 AI 计算平台，实现指定目标识别与低速靠近。

### 1.2 项目目标

1. 实现双轮电机闭环调速，支持前进、后退、转向、定点旋转与停止。
2. 实时获取编码器、姿态和近距离障碍信息，并识别关键数据失效。
3. 同屏显示摄像头画面、机器人运行状态和主要传感器数据。
4. 在已知起点的小场地内完成预设路径点任务，绕过简单静态障碍后继续导航。
5. 在急停、碰撞、控制超时或关键故障发生时停止运动，并记录原因。
6. 通过可重复的测试和演示，证明系统功能、稳定性与安全保护效果。

项目优先完成实时控制、系统稳定性和自主导航，AI 功能作为扩展项。

### 1.3 需求约定

- “应”“必须”表示基础版本需要满足的要求。
- “可选”表示独立扩展范围，不作为基础版本交付的必要条件。
- 性能数值为沿用原方案的拟定设计与验收目标，不表示已经实现；最终测试条件和指标在验收前确认。
- 本文规定系统需要具备的能力。具体算法、RTL 文件划分、寄存器地址和调试步骤由详细设计确定。

## 二、使用场景与项目范围

### 2.1 使用场景

| 场景 | 使用方式 | 预期结果 |
| --- | --- | --- |
| 上电与检查 | 操作者上电并查看状态 | 电机保持禁用，系统报告初始化和自检结果 |
| 手动调试 | 操作者通过调试端发送运动命令 | 小车按指令低速运动，并接受安全限制 |
| 路径点导航 | 设置起点、初始朝向和路径任务 | 小车依次到达目标点，完成后停车 |
| 简单绕障 | 路径上设置可被测距传感器识别的静态障碍 | 小车减速、选择方向、绕行并恢复导航 |
| 异常处理 | 触发急停、碰撞、控制失联或关键传感器故障 | 小车停止，显示并记录原因 |
| AI 演示，可选 | 指定目标并进入 AI 模式 | 小车识别目标、对准并低速靠近，目标丢失后停车 |

### 2.2 基础版本范围

基础版本面向平整室内地面、已知起点和初始朝向、3～5 个预设路径点，以及具有足够绕行空间的简单静态障碍场景。自主运行初始速度范围为 0.15～0.25 m/s，最终限速由制动和感知测试确定。

基础导航采用相对定位。六轴 IMU 与轮式里程计融合仍会产生漂移，路径到达误差应由外部测量验证。

### 2.3 可选扩展与范围边界

- AI 扩展：指定目标识别、目标方位输出、低速对准与靠近；搜索和简单跟随可在该扩展内继续评估。
- LiDAR 扩展：基础功能验收后评估 LD06 接入、感知增强及后续导航方案。
- 基础版本不包含完整 SLAM、绝对无漂移定位、任意复杂环境导航，以及复杂动态障碍处理。
- 三路前向 ToF 的感知范围有限。基础版不要求自主长距离倒车；原地转向须考虑车体侧后方的扫掠空间。

## 三、系统组成与职责

### 3.1 系统分工

| 组成 | 职责 |
| --- | --- |
| FPGA 硬件逻辑（RTL） | 编码器采集、轮速闭环、PWM、驱动输出、安全联锁、时间戳、通信外设及视频流水线 |
| FPGA 内部软核程序 | 传感器初始化与读取、姿态融合、里程计、路径任务、绕障和运行调度 |
| 显示与调试端 | 显示图像和状态，发送任务与调试命令，查看参数和日志 |
| LicheePi 4A，可选 | 目标识别、视觉结果处理与任务请求，通过通信接口接入 FPGA |

导航与 AI 只提交运动目标，最终电机输出由 FPGA 运动控制和安全模块共同管理。安全模块对驱动输出拥有最高优先级的禁止权限。软核方案应与实际 FPGA 型号、工具版本和 BSP 匹配，基础版本采用裸机任务调度。

### 3.2 硬件组成

| 部分 | 现有或候选方案 | 数量 | 约束 |
| --- | --- | ---: | --- |
| 底盘 | 两驱动轮＋两万向轮 | 1 套 | 车架平整，轮径、轮距和车体轮廓需标定 |
| FPGA | 小梅哥 ACG720 | 1 块 | 确认器件型号、板卡版本和可用例程 |
| 电机 | WHEELTEC MG513XP28_12V | 2 台 | 12 V 有刷减速编码电机，分别确认方向和每圈计数 |
| 电机驱动 | 双路 AT8236 模块，2026-10-02 已补 MD-AT8236 V1.0 类接口资料 | 当前原理图预留 2 块、各用 A 通道 | [资料核对](电机/AT8236模块资料核对.md)：VM 标称 5–17 V、每路 3 A/6 A 峰值、VCC 为参考输入；须修正 PCB 对排顺序、实测排距/限流/散热并适配 FPGA 输出 |
| 摄像头 | OV5640 DVP 模块 | 1 个 | 与板卡接口、排线、电平及官方例程兼容 |
| IMU | ICM-42688-P 模块 | 1 个 | 优先 SPI，确认安装方向和坐标系 |
| 测距 | VL53L1X 模块 | 3 个 | 左前、正前、右前，共用 I²C、独立 XSHUT |
| 碰撞检测 | 微动开关＋前保险杠 | 2 个开关＋1 套保险杠 | 直接接入硬件安全逻辑 |
| 显示 | 与板卡视频例程匹配的屏幕或显示器 | 1 套 | 型号和接口待确认 |
| 电源 | 三串LiPo电池、板载总保险、分路稳压、总开关及急停 | 1 套 | 执行器与计算支路分开；总保险位于XT60正极之后、防反接之前；单体电芯保护另行落实 |
| AI 平台，可选 | LicheePi 4A＋Linux UVC 摄像头 | 各 1 个 | 首版 AI 与 FPGA 分别使用摄像头，模型及 NPU 兼容性需验证 |
| LiDAR，可选 | LD06 | 1 个 | 后续扩展评估 |

## 四、功能需求

### 4.1 系统启动与运行管理

| 编号 | 功能 | 需求描述 |
| --- | --- | --- |
| FR-SYS-01 | 上电初始化 | 系统应完成控制、传感器、通信及显示相关初始化并报告结果；上电、复位和程序下载期间电机保持禁用。仅在自检通过、相关数据有效且显式解锁后允许运动。 |
| FR-SYS-02 | 运行模式管理 | 系统应支持手动控制和路径导航；启用 AI 扩展后增加 AI 模式。同一时刻仅允许一个控制模式提交有效运动请求，切换模式时应先停止并使旧命令失效。 |
| FR-SYS-03 | 状态管理 | 系统应区分未解锁、就绪、运行和故障状态，并提供可查询的状态信息。任务完成或停止后应退出运行状态；故障清除后回到未解锁状态。 |

### 4.2 底盘运动与闭环控制

| 编号 | 功能 | 需求描述 |
| --- | --- | --- |
| FR-MOT-01 | 基本运动 | 系统应支持前进、后退、左右转向、定点旋转和停止。自主任务应遵守已确认的速度与转向限制；基础后退动作在受控空旷场地低速验证。 |
| FR-MOT-02 | 轮速闭环 | 系统应分别采集左右轮编码器反馈并进行闭环调速，提供目标轮速、实测轮速及输出状态，支持轮径、编码器计数和控制参数的标定配置。 |
| FR-MOT-03 | 输出约束 | 正常调速应限制速度变化率、输出幅度并保护换向过程；异常编码器反馈应被检测。急停和严重故障应绕过普通调速斜坡，由安全逻辑直接限制最终输出。 |

### 4.3 传感器采集与状态估计

| 编号 | 功能 | 需求描述 |
| --- | --- | --- |
| FR-SEN-01 | 编码器与里程数据 | 系统应提供双轮有符号累计计数、方向、增量和异常跳变信息，两侧向前统一为正，并处理计数回绕与同步读取。 |
| FR-SEN-02 | 姿态与相对航向 | 系统应读取 IMU 数据，支持静止零偏校准和安装坐标变换，输出横滚角、俯仰角及相对初始朝向的航向角，并提供数据有效状态和时间戳。 |
| FR-SEN-03 | 三路距离感知 | 系统应独立识别三颗 ToF，分别输出距离、有效状态与采样时间，识别通信错误和数据过期。测距结果应考虑传感器相对保险杠的安装位置，用于净空判断。 |

### 4.4 摄像头与显示

| 编号 | 功能 | 需求描述 |
| --- | --- | --- |
| FR-VID-01 | 实时视频 | 系统应完成 OV5640 图像采集、缓存和显示。不同采集与显示帧率下应保证帧数据完整，避免持续撕裂、显示卡死或覆盖正在读取的帧。 |
| FR-VID-02 | 状态叠加 | 系统应在视频画面上显示运行模式、当前路径点、姿态、左右轮速、三路距离及故障信息；数据无效或过期时应明确标识，避免将旧值作为有效当前值展示。 |

### 4.5 相对定位与路径点导航

| 编号 | 功能 | 需求描述 |
| --- | --- | --- |
| FR-NAV-01 | 定位初始化 | 系统应支持在静止状态下设置起点和初始朝向，结合编码器与 IMU 更新相对位置和航向，支持轮径、轮距校准及按采样时间对齐数据。 |
| FR-NAV-02 | 路径任务执行 | 系统应支持配置或选择包含 3～5 个路径点的任务，按顺序控制转向与前进、接近目标时减速，满足到达条件后切换目标，全部完成后停车并报告完成状态。 |
| FR-NAV-03 | 任务异常处理 | 系统应支持停止当前任务；定位所需数据失效、命令过期或长期无法接近目标时，应停止并报告原因，等待操作者重新下发任务。 |

### 4.6 避障与导航恢复

| 编号 | 功能 | 需求描述 |
| --- | --- | --- |
| FR-OBS-01 | 减速与保护距离 | 系统应依据当前速度、有效距离和数据时效判断减速及停车条件。距离阈值应覆盖最坏感知与处理延迟、实测制动距离和安全裕量，并具有避免频繁切换的迟滞机制。 |
| FR-OBS-02 | 简单障碍绕行 | 系统应完成减速、选择方向、转离障碍、绕行及恢复原目标导航；设置状态超时、最大绕行距离和尝试次数。无可用方向、碰撞、感知失效或无进展时，应停止并报告原因。 |

### 4.7 安全与故障处理

| 编号 | 功能 | 需求描述 |
| --- | --- | --- |
| FR-SAF-01 | 急停与碰撞联锁 | 急停应通过硬件切断执行器支路；碰撞信号应直接进入硬件安全逻辑，首次触发即发起停止并锁存，不能因常规去抖或导航处理而延迟。 |
| FR-SAF-02 | 超时与故障保护 | 软核心跳超时、当前控制源命令过期、驱动过流或过温、编码器异常，以及当前动作依赖的关键传感器失效时，应禁止相关运动输出并记录原因。基础版前向 ToF 失效时应停车。 |
| FR-SAF-03 | 故障恢复与记录 | 系统应记录故障类型和发生时间，提供查询与清除接口。清除故障、重新解锁、重新下发任务应为明确动作，禁止故障解除或通信恢复后自动继续运动。 |

安全处理优先级为：硬件急停 → 故障与碰撞联锁 → 安全限制 → 当前已授权控制模式。车体从发起停止到完全停住的时间和距离应实测，硬件逻辑响应时间不能替代整车停车时间。

### 4.8 通信、参数与调试

| 编号 | 功能 | 需求描述 |
| --- | --- | --- |
| FR-COM-01 | 命令交互 | 系统应通过 UART 支持解锁、停止、手动速度、路径任务、状态查询及参数设置；报文包含类型、长度、序号、有效期和校验信息，错误或越界命令应被拒绝。 |
| FR-COM-02 | 命令生效与时效 | 左右轮目标与命令有效期应一起生效。有效期按 FPGA 本地接收时间判断，控制源失效后不得持续执行旧运动命令；模式之间不得争夺电机输出。 |
| FR-COM-03 | 状态与日志 | 系统应提供轮速、姿态、距离、任务状态、故障和关键统计信息，支持调参及测试数据记录。调试通信和显示更新不得阻塞关键控制任务。 |

### 4.9 AI 目标识别与靠近，可选

| 编号 | 功能 | 需求描述 |
| --- | --- | --- |
| FR-AI-01 | 视觉目标信息 | 扩展平台应识别指定目标，通过 UART 输出类别、置信度、图像中心偏差、框大小、序号及有效期；应测量处理延迟并丢弃积压图像，基础接口不传原始视频。 |
| FR-AI-02 | 目标对准与靠近 | 进入 AI 模式后，小车应根据有效视觉信息对准目标并低速靠近，由 ToF 施加距离安全限制；目标丢失、数据过期、通信失联或近障碍触发时停车。 |

AI 演示面向目标居中、视线简单、无其他近障碍的受控场景。前向 ToF 的读数用于保守安全限制，不保证等于被识别目标的距离。AI 平台不得绕过 FPGA 的轮速闭环和安全保护。

## 五、接口与系统约束

### 5.1 硬件及通信接口

| 接口 | 要求 |
| --- | --- |
| 电源与急停 | 执行器、FPGA、传感器及可选 AI 支路按各自电压和负载供电，配置板载总保险、单体电芯保护、电机电子过流关断及适合直流负载的急停切断装置；检查瞬态、回生、接地和峰值负载。 |
| 电机与编码器 | 驱动接口适配 3.3 V 逻辑及实际 IO Bank 电压；驱动使能应具有默认禁用措施。编码器供电与输出电平分别核实。 |
| IMU | 优先采用 SPI，支持器件初始化、数据读取、有效状态与采样时间获取。 |
| 三路 ToF | 共用 I²C、独立 XSHUT，上电逐颗分配地址；核实上拉电压和地址表示方式，避免模块冲突。 |
| 摄像头与显示 | 摄像头 DVP、配置接口及显示接口应与实物板卡和例程匹配，明确时钟、引脚、电平及格式。 |
| 外部 UART | 双方约定波特率和报文格式，支持长度检查、序号、命令有效期和 CRC16 校验；未同步时钟时不直接使用外部时间判断 FPGA 超时。 |
| 软核与 RTL | 通过约定的寄存器接口交换数据和命令，保证多字段命令原子提交、状态一致性快照及跨时钟域数据完整性。 |

### 5.2 公共数据约定

| 数据 | 统一约定 |
| --- | --- |
| 编码器 | 有符号累计计数，两侧向前均为正，定义回绕处理 |
| 轮速与距离 | 对外使用 mm/s 和 mm，定点格式统一；传感器数据附有效标志和采样时间 |
| 位置与角度 | 计算统一使用 m、rad；寄存器可使用 mm、mrad，转换方式在接口文档中固定 |
| 时间 | FPGA 本地时间基准，定义位宽、精度和回绕比较规则 |
| 控制命令 | 模式、目标、序号、有效期和原子生效机制 |
| 故障 | 故障码或位图、发生时间、当前状态及清除条件 |

软核执行、视频缓存和显示访问应避免相互阻塞。若共享外部存储，应验证视频满负载下的最坏控制访问延迟。多位跨时钟域数据应使用握手、FIFO 或一致性快照等机制。

## 六、性能与质量要求

### 6.1 拟定验收指标

以下目标沿用原实施方案。正式测试前应固定速度、载荷、电量范围、地面、障碍布局和测量方法；结果以实测记录为准，不能通过临时放宽条件判定通过。

| 编号 | 项目 | 拟定目标 |
| --- | --- | --- |
| NFR-01 | 轮速精度 | 在明确的非低速测试区间，左右轮稳态误差均争取 ≤5%；低速表现单独记录 |
| NFR-02 | 直行与转向 | 2 m 直线路段横向偏差争取 ≤10 cm；90° 定点转向误差争取 ≤5° |
| NFR-03 | 路径点到达 | 受控场地到达半径先设 15 cm，稳定后可尝试 10 cm；采用外部实际测量 |
| NFR-04 | 绕障成功率 | 固定简单场景连续测试 10 次，争取至少 9 次无碰撞绕行并恢复导航至终点 |
| NFR-05 | 视频显示 | 例程支持时以 640×480、RGB565、约 30 fps 为初始目标，连续运行 30 min 无明显撕裂或卡死 |
| NFR-06 | 整车稳定性 | 控制、传感器、通信和显示同时工作，连续运行 30 min 无意外复位或失控 |
| NFR-07 | 安全保护 | 急停、碰撞、控制超时、软核失效及关键传感器故障均触发预期停止并留下实测记录 |
| NFR-08 | 实时性 | 关键任务周期和最坏延迟可测量；视频、日志负载下仍满足已确定的控制周期及停车净空要求 |

### 6.2 设计参考值

以下为详细设计与调试的起点，不单独作为功能验收结果。

| 项目 | 参考值或要求 |
| --- | --- |
| 轮速闭环 | 约 100 Hz 更新 |
| PWM | 驱动支持时以 20 kHz 起步 |
| IMU 采样与融合 | 约 200 Hz，按实际采样时间处理 |
| ToF | 每路以 20～30 Hz 为目标，按测量预算和干扰测试确认真实刷新率 |
| 导航 | 20～50 Hz |
| 状态显示与遥测 | 10～20 Hz |
| 自主速度 | 初始限制在 0.15～0.25 m/s，按实测停车能力调整 |

停止距离阈值应包含感知和处理延迟期间的行驶距离、制动距离及安装净空裕量。心跳与命令超时值应根据任务调度和停车距离确定，不能只按软件循环频率设定。

## 七、验收方案

### 7.1 验收条件与判定

验收使用实际整车、固定版本工程和参数配置，记录环境、载荷、电池状态及测量工具。运动精度应由外部距离和角度测量验证；安全逻辑延迟与整车停车时间分别测量。

基础版验收应覆盖所有必选功能及确认后的性能目标。可选 AI 功能单独验收。测试中的故障和未达标项应记录原因、处理结果与复测结论。

### 7.2 功能验收项目

| 测试项 | 对应需求 | 测试内容及通过依据 |
| --- | --- | --- |
| 启动与模式 | FR-SYS-01、FR-SYS-02、FR-SYS-03 | 检查上电、复位、下载和模式切换；电机默认禁用，状态正确，切换后旧命令不能继续驱动 |
| 电机运动与反馈 | FR-MOT-01、FR-MOT-02、FR-MOT-03、FR-SEN-01；NFR-01 | 验证基本动作、正反向计数、轮速阶跃、换向及输出限制；反馈符号正确，满足确认后的轮速目标 |
| 姿态与测距 | FR-SEN-02、FR-SEN-03 | 验证姿态变化、三路测距、数据时效及传感器断开；数值与实际变化一致，失效可识别 |
| 视频与叠加 | FR-VID-01、FR-VID-02；NFR-05 | 连续显示摄像头画面，检查状态同步更新和无效值标识，达到确认后的显示稳定性目标 |
| 相对定位与路径 | FR-NAV-01、FR-NAV-02、FR-NAV-03；NFR-02、NFR-03 | 完成标定、无障碍多点路线、停止及无进展测试；以外部测量检查精度，到终点停车并报告完成 |
| 绕障与恢复 | FR-OBS-01、FR-OBS-02；NFR-04 | 验证减速、绕行、恢复原任务，以及无路可走和超时情况；成功率达标，失败场景正确停车 |
| 安全联锁 | FR-SAF-01、FR-SAF-02、FR-SAF-03；NFR-07 | 触发急停、碰撞、当前控制源失联、软核卡死、关键传感器断开，并通过受控故障输入验证驱动和编码器异常保护；停止并记录原因，恢复后不自动运动 |
| 通信与调试 | FR-COM-01、FR-COM-02、FR-COM-03 | 发送正常、校验错误、越界和过期命令，查询状态与参数；正确执行或拒绝，双轮命令一致生效，日志可记录 |
| 综合运行 | NFR-06、NFR-08 | 同时启用运动、感知、视频和通信，测量任务周期、最坏延迟与稳定性，验证实际停车净空 |
| AI 扩展，可选 | FR-AI-01、FR-AI-02 | 验证识别、对准、低速靠近及目标丢失、遮挡、旧图像和串口断开；无效输入不导致持续运动 |

### 7.3 验收记录

应交付轮速阶跃曲线、制动距离记录、路径重复实验结果、故障注入记录、综合运行日志或视频，以及 FPGA 时序和资源报告。各项记录标明工程版本、参数与测试条件。

驱动异常验证采用受控限流、安全负载或故障信号注入方式；制动测试覆盖不同速度、载荷、电量和地面条件。

## 八、项目交付物

| 交付物 | 内容要求 |
| --- | --- |
| 整车系统 | 可重复运行的硬件、布线、供电、急停和传感器安装 |
| FPGA 工程 | RTL、IP 配置、引脚与时序约束，以及可复现的构建和下载说明 |
| 软核固件 | BSP、驱动、控制与导航程序，编译方法和参数配置 |
| 接口文档 | 接线供电、坐标系与单位、寄存器接口、UART 协议和故障定义 |
| 测试资料 | 仿真或模块测试、整车验收记录、问题处理与复测结果 |
| 使用说明 | 上电、自检、解锁、手动调试、任务启动、停止和故障恢复操作 |
| 展示资料 | 功能演示视频、性能结果和项目说明 |
| AI 扩展资料，可选 | 模型与运行环境、通信适配、性能测量和异常停车测试记录 |

每个核心模块应具备接口说明、可运行实现、测试方法和测试记录。具体目录与代码组织在工程设计阶段确定。

## 九、项目阶段与里程碑

项目按阶段组织，不规定逐周任务。各阶段以可验证结果作为完成条件，实际工期根据硬件到位和联调情况安排。

| 阶段 | 主要内容 | 阶段完成条件 |
| --- | --- | --- |
| 基础确认与平台搭建 | 确认需求、硬件、供电、接口和测试场地；验证软核及视频基础例程 | 电气与接口条件明确，急停有效，上电及复位不转轮，单轮反馈与调速可用 |
| 核心功能开发与集成 | 双轮闭环、传感器、通信、安全联锁、视频和状态显示 | 基本运动、感知、显示可同时运行，关键异常可检测并停车 |
| 自主任务与整车验证 | 里程计标定、路径点导航、绕障恢复及故障测试 | 在约定场景完成路径和绕障任务，达到确认后的性能与稳定性目标 |
| 验收与交付 | 固定工程和参数，完成复测、文档及演示 | 必选需求验收完成，交付物齐全，操作和演示可重复 |

AI 扩展在核心功能稳定后单独推进和验收；LiDAR 另行评估。工期受限时优先调整可选扩展范围，基础安全与整车验收仍作为交付条件。

## 十、待确认事项与实施依赖

| 事项 | 待确认内容 | 影响 |
| --- | --- | --- |
| 板卡版本 | 实物 FPGA 型号、板卡版本、IO Bank 电压、供电范围 | 软核、引脚约束、摄像头、DDR 和显示方案 |
| 例程与工具 | Gowin 工具版本、BSP、软核及视频例程兼容性 | 基础工程能否构建、下载和运行 |
| 电机驱动 | 最终型号、持续电流、散热、限流、电流反馈与故障接口 | 输出能力及故障保护 |
| 供电方案 | 电池串数、容量、满电电压、峰值放电及各支路稳压 | 整车稳定性与电气安全 |
| 机械参数 | 左右有效轮径、有效轮距、车体轮廓和传感器位置 | 里程计精度、转向和停车净空 |
| 编码器 | 两台电机每输出轴转计数、输出电平及正反方向 | 轮速闭环和里程计 |
| 传感器安装 | IMU 安装坐标、ToF 角度、XSHUT 和上拉电压 | 姿态、地址分配及可感知范围 |
| 验收条件 | 场地、载荷、电池范围、障碍布局、测量方法和最终指标 | 测试结果可重复性 |

现有电机资料标称减速比 1:28、额定电流 0.36 A、堵转电流 3.2 A，均为单台参数，驱动选型仍须结合实际负载验证。若编码器 13 PPR 表示电机轴每相周期数，则四倍频理论值为 1456 counts/输出轴转；实际采用左右电机各自标定值。

原资料中的 ACG720 输入范围为 6～12 V，仍须按实物手册确认。普通三串锂电池满电可达 12.6 V，应根据确认后的允许范围设计供电，不能仅凭电池标称电压直接接入板卡。

## 十一、参考资料

详细实现思路、算法、模块划分及原始进度建议保存在[原实施方案](reference/robot_implementation_plan.md)，供详细设计时参考；本项目的功能范围与验收要求以本需求书为准。

以下为原方案所列官方资料入口，器件参数、版本和适配条件在详细设计时核对：

- [东芝 TB6612FNG 数据手册](https://toshiba.semicon-storage.com/info/TB6612FNG_datasheet_en_20141001.pdf?did=10660&prodName=TB6612FNG)
- [TI DRV8874 产品资料](https://www.ti.com/product/DRV8874)
- [Gowin PicoRV32 官方介绍](https://www.gowinsemi.com/en/support/ip_detail/46/)
- [TDK ICM-42688-P 数据手册](https://product.tdk.com/system/files/dam/doc/product/sensor/mortion-inertial/imu/data_sheet/ds-000347-icm-42688-p-v1.6.pdf)
- [ST VL53L1X 数据手册](https://www.st.com/resource/en/datasheet/vl53l1x.pdf)
- [ST VL53L1X ULD 驱动](https://www.st.com/en/embedded-software/stsw-img009.html)
- [Sipeed LicheePi 4A NPU 使用文档](https://wiki.sipeed.com/hardware/zh/lichee/th1520/lpi4a/6_peripheral.html)

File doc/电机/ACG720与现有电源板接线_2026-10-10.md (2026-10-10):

# ACG720 与现有 AT8236 电源板接线

核对日期为 2026-10-10。本文针对用户正在使用、于 2026-10-09 更新的嘉立创 EDA 电源板，依据用户提供的原理图 PDF、SVG、PCB PDF 和 PCB 截图。仓库内多页 KiCad 改版的 J1/J2 接口定义不用于本板。

## 接线结论

使用 P7-1～4 连接左轮，P7-31～34 连接右轮，共八根信号线。P7-5～10、P7-35～40 保留。摄像头现有连接保留。

这是一份固定的引脚分配。摄像头 DDR 自检固件没有这些电机控制端口；既有 PID 工程的底层驱动面向 TB6612，不能直接套用。最初的接线核对没有修改 RTL 或上板；用户接线完成后，于 2026-10-10 新建 [AT8236 独立电机测试工程](../../code/fpga/acg720-motor-test/README.md)，完成仿真、实际管脚核对、50 MHz 时序检查及 SRAM 下载（User Code `0xA710`）。S1 测左轮、S2 测右轮，最高 25% 占空比，约 2 秒自动停止，S0 停止。实物转动结果须由用户观察确认。

| 用途 | FPGA P7 针号 | FPGA 管脚 | 电源板接口 | 原理图网络 | 相对 FPGA 的方向 |
| --- | --- | --- | --- | --- | --- |
| 左轮驱动输入 1 | 1 | A13 | L-1 | LAIN1 | 输出 |
| 左轮驱动输入 2 | 2 | A14 | L-2 | LAIN2 | 输出 |
| 左轮编码器 A | 3 | A15 | L-7 | LF_ENA | 输入 |
| 左轮编码器 B | 4 | A16 | L-8 | LF_ENB | 输入 |
| 右轮驱动输入 1 | 31 | F16 | R-5 | RAIN1 | 输出 |
| 右轮驱动输入 2 | 32 | E17 | R-6 | RAIN2 | 输出 |
| 右轮编码器 A | 33 | D20 | R-2 | RF_ENA | 输入 |
| 右轮编码器 B | 34 | C20 | R-1 | RF_ENB | 输入 |

ENA/ENB 在这张图中是编码器反馈，并非驱动使能。四个编码器网络直接连到排针，没有额外电平转换，接入前应确认编码器供电和高电平为 3.3 V。

## 电源板接口位置与完整针序

以用户 PCB 截图方向观察，XT60 在左上，两个 USB-C 在上方，两只电机插座在下方。两排八针控制接口位于电机插座上方。

- 图中左侧八针排针标记为 **R**，控制右电机。
- 图中右侧八针排针标记为 **L**，控制左电机。
- 两排的最左端均为方形焊盘，也就是 1 脚，均从左向右数 1～8。原理图符号中 R 的上下顺序与 L 相反，不能照原理图的视觉顺序数 PCB 针脚。

| 针号 | L 接口，图中右侧 | R 接口，图中左侧 |
| --- | --- | --- |
| 1 | LAIN1 | RF_ENB |
| 2 | LAIN2 | RF_ENA |
| 3 | LBIN1 | 3.3V |
| 4 | LBIN2 | GND |
| 5 | GND | RAIN1 |
| 6 | 3.3V | RAIN2 |
| 7 | LF_ENA | RBIN1 |
| 8 | LF_ENB | RBIN2 |

当前每块 AT8236 模块使用 A 通道带一台电机，B 通道输出没有连接到电机。L-3、L-4 接本板 GND（可接 L-5），R-7、R-8 接本板 GND（可接 R-4），使未使用 B 通道输入保持 0。不要把这些输入误当作反馈端。

图中左电机的六针插座在右侧、右电机的六针插座在左侧，两者的逻辑针序一致。这里只记录板端网络，不据此认定电机线束颜色或编码器版本的线序已经实测通过。

| 电机插座针号 | 左电机网络 | 右电机网络 |
| --- | --- | --- |
| 1 | LAOUT2 | RAOUT2 |
| 2 | 3.3V | 3.3V |
| 3 | LF_ENA | RF_ENA |
| 4 | LF_ENB | RF_ENB |
| 5 | GND | GND |
| 6 | LAOUT1 | RAOUT1 |

### 2026-10-10 实物电机照片确认

用户新增电机尾部照片，六针插座旁丝印从照片上到下依次为“电机线+、编码器 GND、编码器 B 相、编码器 A 相、编码器 5V、电机线-”。实物为裸露霍尔编码器电路板。用户说明这六根线从上到下，对应现有 PCB 右下方左电机插座从右到左；由上述板端针序得到：

| 照片从上到下 | 左电机插座针号（PCB 图从左往右数） | 板端网络 | 逻辑对应 |
| --- | --- | --- | --- |
| 电机线+ | 6 | LAOUT1 | 正确 |
| 编码器 GND | 5 | GND | 正确 |
| 编码器 B 相 | 4 | LF_ENB | 正确 |
| 编码器 A 相 | 3 | LF_ENA | 正确 |
| 编码器 5V | 2 | 3.3V | 供电正极位置对应；本批次 3.3 V 工作情况仍需电平验证 |
| 电机线- | 1 | LAOUT2 | 正确 |

该确认来自照片丝印和用户的线束对应描述，并不替代逐线导通测量。不要交换编码器 A/B 或反转六针插头作为排查手段。电机两根功率线仅连接 AT8236 桥输出，不连接固定 12 V 或 FPGA IO。WHEELTEC 官方 MG513X 产品页的编码器参数图给出 3.3～5 V 供电；照片板上印 5V，故不能凭丝印就判定当前 3.3 V 一定不兼容，也不能凭系列参数保证该实物在 3.3 V 下正常。若后续需要试编码器 5 V，必须单独处理编码器电源和 A/B 电平转换；本板共用 3.3 V 网还连接 FPGA 电源与模块参考端，不得整体改接 5 V。

用户在 A710 测试固件下实测：L-1 对 L-5 在 S1 运行阶段约 0.8 V，左电机六针插座 2 对 5 为 3.3 V；手转左轮时 L-7 会到约 2.3 V，L-8 持续约 2.3 V，D3/D4 仍未见活动。尚待区分电压为停止后的稳定值还是转动平均值，并测模块本体 AIN1/AIN2 和左电机插座 6 对 1 的驱动输出，不能据此确定硬件损坏或仅归因于 PWM。

后续用户测左电机插座 6 对 1 最高约 0.05 V；模块本体 VCC 对 GND 为 3.3 V、VM 为 12 V，AIN1/AIN2 未测出电压。已确认测的是 PCB 图右侧、L 上方的左轮模块。A711 的 1 kHz/25% 对照下两轮仍未转，S1 时有电机声音；输入端读数与此前 L-1 的 0.8 V 不一致，尚需区分短测量窗口、表笔接触、通道/安装方向及导通问题。不能由声音判断桥输出已正常。

此前 A712 已下载至 SRAM（`0x0000A712`）：相同接线、1 kHz、最高 50%、每次 1 秒自动停止，用于短时启动对照。仿真、21 个实际管脚及 50 MHz 时序检查通过；用户在逐轮测试提示后回复“转了，亮了”，确认电机转动及编码器活动。对照支持此前启动激励不足，尚未测量实际电流和最低启动阈值；活动灯也不代表 A/B 相、方向或计数已完整验证。完整方法及证据见 [电机启动排查与实现文档](../../code/fpga/acg720-motor-test/MOTOR-IMPLEMENTATION-2026-10-10.md)。

用户随后要求持续运行、再次按键停止及提高速度。相同接线下 A713（1 kHz/65%）获用户确认左右启停正常；A714（1 kHz/80%）用户感觉未明显变快。20 kHz/80% 的 A715 编译后未下载，用户改为“直接上50kHz”。当前已下载 **A716（`0x0000A716`）：50 kHz、最高 80%**，S1/S2 分别切换左右轮，允许同时运行，S0 停止全部输出。持续版没有自动超时，D5 为两轮均停止；A716 实际运行和速度变化待反馈。A712/A713/A714 位流均保留供对照。

## 3.3 V 和共地须另接

这张原理图中 U1、U5 两路 MP2236 均配置为 5 V 输出，分别供 USB-C。标为 `3.3V` 的网络连接 L-6、R-3、驱动模块参考输入以及两个编码器电源脚，图中没有该网络的板上稳压来源。AT8236 模块的 VCC 为参考输入，也不提供这路电源。

ACG720 官方通用原理图第 1 页给出 P8 为 2×4 排针，其中 P8-7 接 VCC3V3，P8-8 接 GND。**P8 与调节 VCCIO 的 P6 不是同一个接口。**

若 P8 未占用，推荐接法为：

| 电源线 | ACG720 端 | 电源板端 |
| --- | --- | --- |
| 3.3 V 电源 | P8-7 | L-6 |
| 信号公共地 | P8-8 | L-5 |

原理图中 L-6 与 R-3 同属 `3.3V`，L-5 与 R-4 同属 `GND`，因此按图纸只接这一组即可给两侧提供共同参考。首次连接前用断电导通测量确认实物确实同网；也可分别给两侧接地线以减少长线干扰。

若 P8 不可用，可从摄像头现有 P7-29（VCC3V3）和 P7-30（GND）线路分支引出；P7-12 也是 GND。保留摄像头连接，不要用普通 IO 输出恒定高/低电平来替代供电或接地。

用户随后提供实物照片，确认 USB J2 下方黄色 2×10 摄像头接口为 **P4**。按照片 USB 在上、HDMI2 在下的方向，左列奇数、右列偶数，上端第一对为 P4-1/P4-2。官方原理图第 11 页给出 **P4-1 为经 FB4 磁珠引出的 3.3 V、P4-2 为 GND**；若该接口未使用，也可分别连接 L-6、L-5，给编码器及驱动参考端供电。三种供电接法选一组即可。

这路 3.3 V 用于编码器和参考端，不给电机功率部分供电。若这块电源板已经另接独立 3.3 V 稳压器，则只需共地，不应将两个稳压器输出直接并联。接入 FPGA 电源时，应核实剩余负载能力，避免电机运行使编码器线路上的干扰影响 FPGA 或摄像头供电。

用户可用的 P7-1～10、P7-31～40 全部为信号 IO，其中没有电源或地。不要把 5 V、VM、电机 AOUT1/AOUT2 接入这些引脚。

## FPGA P7 的数针方向

ACG720 正面朝上，HDMI 在左、DC 电源在右上时，P7 位于上边缘。

- 靠 PCB 外边的上排为偶数，左到右为 2、4、6……40。
- 靠 FPGA 的下排为奇数，左到右为 1、3、5……39。
- 左端下排方形焊盘为 1 脚；背面视图左右反转，不能按本图方向直接数。
- P7-11 是 5 V，P7-12 是 GND，P7-29 是 3.3 V，P7-30 是 GND。

针号与 FPGA 管脚对应已同时核对官方通用原理图第 11 页及《高云 ACG720-138&60K通用管脚分配表》的 GPIO0 条目。上述八个管脚在现有摄像头自检工程的显式 CST 中未占用；本方案全部使用 3.3 V IO，实际 P7 Bank2 的 VCCIO 也应为 3.3 V。

## 后续固件实现边界

AT8236 每台电机用两个输入控制，不具备 TB6612 的独立 PWM/STBY 排针。按芯片原厂表，快衰减 PWM 接法为：

| 目标状态 | AIN1 | AIN2 |
| --- | --- | --- |
| 复位 / 禁止 / 滑行 | 0 | 0 |
| 一个方向调速 | PWM | 0 |
| 另一个方向调速 | 0 | PWM |
| 主动制动 | 1 | 1 |

这里的两个方向只是桥输出方向，车身前进方向还要结合左右电机安装方向验证。将旧 TB6612 工程的静态方向脚直接接到 AIN、丢弃原 PWM 脚，会失去正确调速能力。后续需生成四路 AT8236 输入，并保证启动、复位和禁用期间均为 0；编码器四路作为异步输入同步到 FPGA 系统时钟后再计数。

接线应在两块板均断电时完成。用户已报告按本方案接线；独立测试固件的约束检查、编译及 SRAM 下载已经完成，接下来架空车轮，逐轮按键测试。电源电压、线束导通、手转编码器计数及实际电机旋转仍不能由软件检查代替。

## 核对来源

- 用户提供 `C:/Users/sc/Downloads/SCH_Schematic1_2026-10-09.pdf` 与同页 SVG，核对 L/R 排针针号、网络及 3.3 V 电源来源。
- 用户提供 `C:/Users/sc/Downloads/PCB_PCB1_2026-10-09.pdf` 第 1 页及 PCB 截图，核对 L/R 物理位置及方形 1 脚焊盘。
- 官方资料包 `06_硬件图纸/ACG720-138&60K通用原理图.pdf` 第 1、2、11、12 页及 `04_引脚功能信息/高云 ACG720-138&60K通用管脚分配表.xlsx`，核对 P8 电源、P7 信号管脚及 Bank2 电压来源。
- [杭州中科微 AT8236-S409-V1.1 原厂手册镜像](https://atta.szlcsc.com/upload/public/pdf/source/20210923/1552D95CBAF8BE780D06AE79E7783380.pdf) 第 2、4、5 页，核对 IN 电平条件、内置下拉和控制真值表。
- 项目 `doc/电机/AT8236模块资料核对.md` 中记录的用户模块资料，核对 VCC 为参考输入，现有双模块各用 A 通道。

用户进一步要求完整排针在同一张图中连线，已绘制 `output/pdf/ACG720-AT8236-full-header-wiring-2026-10-10.pdf` 及同名 PNG。图中完整显示 P7 的 40 针、电源板 R/L 八针控制接口及下方六针电机插座；八根信号线逐根连到实际针号。红黑虚线为 P7-29/30 的电源分支参考，保留摄像头供电；也可用 P8-7/8 替代。线条交叉处不相连；黑色短线表示未用 B 通道输入接本板公共地。两板均为正面视图，P7 数针方向及电源板 R 在左、L 在右的位置保留；图示不按实际尺寸比例绘制。

逐根对应的简明接线图保留于 `output/pdf/ACG720-AT8236-direct-wiring-2026-10-10.pdf`。第一张图为八根信号线，第二张图为电源、公共地、未用通道及 P7 数针方向。多根线需要连接同一个 GND 脚时，应使用分线接头或焊接短线。

原位置参考图保留于 `output/pdf/ACG720-AT8236-motor-wiring-2026-10-10.pdf`。

按用户最新局部截图重新排布的接线图为 `output/pdf/ACG720-AT8236-layout-matched-wiring-2026-10-10.pdf` 及同名 PNG，接线时优先参考这一版。完整 P7 与电源板置于同一页，R 在左、L 在右；下方六针电机插座保留截图中的横向偏移。上排控制接口从左到右均为 1～8，下排电机插座从左到右均为 1～6，方形焊盘为 1 脚；每个针脚均标明网络名称，八根 FPGA 信号线接到上排八针接口，电机线束保持原接法。

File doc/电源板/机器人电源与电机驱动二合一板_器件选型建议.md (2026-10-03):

# 机器人电源＋电机驱动二合一板器件选型建议

> **2026-10-03 当前原理图更新：**两路MP2236供5V、独立AP63203供3.3V、六针USB-C供电口、双路AT8236模块。取消F2/F3，保留电子过流关断；总保险F1使用国产集电通0297010.J，MINI插片10A/32V，按后续要求绑定板载四孔保险座及模型，位于XT60正极之后、防反接之前；保险座孔中心距9.92×3.40mm、钻孔1.78mm，国产同孔位座待核对。用户电池标签为11.1V、3600mAh、35C锂聚合物，照片不能确认保护板，单体电芯保护仍须落实。本文早期“主保险丝/支路保险”及芯片选型比较不代表当前物料，当前方案及购买链接见 [第二版原理图修改说明](../../pcb/power/kicad/review/原理图修改说明_R2.md)。

> **2026-10-02 方案状态：**用户已确认采用双路 AT8236 模块并补充资料图。本文 DRV8874 等内容保留为历史选型比较，不再作为当前电源板必须采用的驱动器件。资料已明确 VCC 为参考输入和两排线序；PCB 对排顺序需修正，孔中心距、实际限流和散热尚需核实。见 [AT8236 模块资料核对](../电机/AT8236模块资料核对.md) 与 [电源板审查与修改清单](../../pcb/power/kicad/review/电源板审查与修改清单.md)。

> 依据用户提供的《文档》《电源预算与架构初稿》《拟用电机资料核对》整理。目标平台：嘉立创EDA/JLCPCB SMT、立创商城（LCSC）中国站采购。
>
> 价格和库存为检索时页面显示值，仅用于比较性价比；下单前必须重新核对库存、封装、数据手册与基础库/扩展库属性。

## 1. 结论先行

建议第一版采用以下主架构：

```text
3S Li-Po（约 9~12.6V）
  │
  ├─ XT60/大电流端子 → 主保险丝 → 防反接MOS → TVS/母线电容 → VBAT
  │
  ├─ DRV8874 ×2 → MG513 直流减速电机 ×2
  ├─ DRV8825 ×2 → 42BYGH34-401A 步进电机 ×2（若本车确实需要）
  ├─ SY8368A 5V降压 ×1 → TPS25810 → USB-C → ACG720 FPGA
  ├─ SY8368A 5V降压 ×1 → TPS25810 → USB-C → Lichee Pi 4A
  └─ 5V支路 → 低噪声3.3V稳压 → 编码器、IMU、ToF
```

### 核心推荐

1. **MG513 驱动继续采用 DRV8874PWPR ×2**，不要退回 TB6612FNG。
2. **两个计算板必须使用两个独立5V降压级和两个独立USB-C源端**，不共用一颗3A降压器，也不把两路5V输出并联。
3. USB-C 每口优先使用 **TPS25810RVCR**，它同时完成CC识别、3A电流宣告、受控VBUS和端口保护，比“仅两只Rp电阻＋5V直连插座”更适合机器人电源板。
4. 每路5V降压优先评估 **SY8368AQQC（固定5V、8A同步降压）**。虽然8A标称有余量，但价格低、瞬态余量大，USB-C端再由TPS25810限制到规范的3A。
5. 若两只42步进电机确实会上车，使用 **DRV8825PWPR ×2**；若只是未来扩展，建议首板保留接口和可选焊盘，不一定立即焊接，以降低成本、面积和热负荷。
6. 建议至少使用 **4层板、2oz外层铜**；如果坚持2层板，必须明显加宽/铺铜、增加过孔阵列并降低对连续大电流能力的预期。

---

## 2. 已确认的主要电气需求

| 项目 | 需求/边界 |
|---|---|
| 电池 | 3S Li-Po，11.1V标称，满电约12.6V，3600mAh |
| 底盘电机 | MG513XP28_12V ×2，单台额定0.36A、堵转3.2A |
| 步进电机 | 42BYGH34-401A ×2，1.5A/相，两相四线 |
| FPGA | ACG720，目标经独立USB-C输入5V；必须先确认该Type-C口确实支持整板供电 |
| AI板 | Lichee Pi 4A，经独立USB-C输入5V，建议5V/3A |
| 传感器 | 编码器×2、ICM-42688-P、VL53L1X；建议3.3V/0.5A以上 |
| 控制电平 | FPGA侧按3.3V逻辑设计 |
| 电机急停 | 切断/禁止电机驱动，但尽量保留计算板供电以记录故障、让Linux正常关机 |

### 定板前最大的前置条件

**必须先确认ACG720对应硬件版本的Type-C口是整板5V供电口，而不只是USB-UART/JTAG/通信口。**需要确认：

- VBUS是否进入主电源路径；
- 允许输入电流；
- 是否需要电源选择开关；
- 与原DC输入口之间有无防反灌；
- 带OV5640时的启动和峰值电流。

确认之前可以完成原理图框架和PCB预布局，但不建议直接投板。

---

## 3. 主芯片选型与立创采购建议

## 3.1 两路5V大电流降压

### 推荐：SY8368AQQC ×2

| 项目 | 内容 |
|---|---|
| 厂牌/型号 | Silergy 矽力杰 SY8368AQQC |
| 立创编号 | **C207642** |
| 封装 | QFN-12 3×3mm |
| 输入范围 | 4~28V |
| 输出 | 固定5V，标称连续8A |
| 检索库存 | 约14K+ |
| 检索单价 | 1+约¥5.10；10+约¥4.10 |
| 用量 | 2颗，ACG720和Lichee Pi各一颗 |

**选择理由：**

- 3S电池全电压范围内可工作；
- 同步降压效率和热表现优于TPS54331、MP1584一类非同步3A方案；
- 价格不高，却能为3A USB-C负载留出足够的负载瞬态余量；
- 两路完全独立，可减少Lichee Pi负载突变对FPGA电源的影响。

**注意：**

- “8A”不是PCB做好后就一定能长期输出8A；电感、输入输出电容、散热焊盘、铜皮面积和环境温度共同决定能力。
- 本项目每路只按USB-C 5V/3A对外使用，不宣告4A或8A。
- 必须按原厂参考设计核算电感饱和电流、纹波电流和环路相关器件。

### 不建议作为主5V/3A口的方案

| 器件 | 不作为首选的原因 |
|---|---|
| TPS54331DR（C9865） | 价格低、库存大，但为非同步3A芯片；3A即接近上限，二极管损耗与发热较大，给Linux板供电余量不足 |
| MP1584EN-LF-Z（C15051） | 也是非同步3A方案；当前小批量页面价格不占优势，且3A输出没有足够余量 |
| TPS62133RGTR（C73973） | 固定5V/3A、性能好，但1+约¥10.28，电流仍只有3A，综合性价比低于SY8368A |

---

## 3.2 USB-C 5V源端控制

### 推荐：TPS25810RVCR ×2

| 项目 | 内容 |
|---|---|
| 厂牌/型号 | TI TPS25810RVCR |
| 立创编号 | **C473913** |
| 封装 | WQFN-20-EP 3×4mm |
| 工作电压 | 4.5~6.5V |
| 功能 | USB-C DFP源端、连接检测、STD/1.5A/3A宣告、受控VBUS、放电与保护 |
| 检索库存 | 约861 |
| 检索单价 | 1+约¥4.28；10+约¥3.46 |
| 用量 | 每个USB-C口1颗，共2颗 |

**推荐原因：**固定5V、最高3A的USB-C供电不需要USB-PD协商，但仍不能只把5V直接连到Type-C插座。TPS25810能以较低成本完成规范的CC宣告和受控VBUS，适合本项目。

设计要求：

- 配置为5V/3A电流能力宣告；
- VBUS从对应SY8368A输出进入TPS25810，再进入插座；
- 每个口各自保留故障状态、使能控制和测试点；
- 两个端口的VBUS绝不能硬并联；
- USB-C只走供电时，D+/D−、高速线可不接，但需在原理图明确NC；
- 每口增加低电容ESD器件保护CC脚，VBUS使用适合5V电源口的TVS/ESD器件。

### USB-C插座

初选 **GCT USB4105-GF-A-120，立创编号C5184243**，16P Type-C母座，检索1+约¥5.62、库存约3.8K。

但连接器属于机械关键件，定板前必须再核对：

- VBUS触点额定电流不低于3A；
- 外壳固定脚形式和PCB厚度匹配；
- 插拔寿命；
- 嘉立创EDA封装尺寸与原厂图纸完全一致；
- 尽量选带通孔外壳固定脚的型号，避免机器人振动导致纯贴片插座脱焊。

---

## 3.3 MG513直流电机驱动

### 推荐：DRV8874PWPR ×2

| 项目 | 内容 |
|---|---|
| 厂牌/型号 | TI DRV8874PWPR |
| 立创编号 | **C1855818** |
| 封装 | HTSSOP-16-EP |
| 电机电压 | 可覆盖3S电池母线 |
| 功能 | 单路全桥、3.3V逻辑、电流检测/限流、故障输出 |
| 检索库存 | 约28K+ |
| 检索单价 | 1+约¥6.30；10+约¥5.47；30+约¥4.68 |
| 用量 | 2颗，每台MG513独占一颗 |

这是当前方案中合理且性价比较高的选型。相比TB6612FNG，DRV8874的电流余量、限流、电流反馈和故障诊断更适合堵转电流3.2A的MG513。

### 建议初始限流

文档中的初值可继续作为打样起点：

- VREF分压：13kΩ/20kΩ；
- IPROPI电阻：约1.8kΩ；
- 目标典型斩波阈值：约2.4A/台。

但必须根据所用DRV8874数据手册版本重新计算，首板把VREF分压下臂和IPROPI电阻做成易替换封装，并预留测试点。2.4A限流值不是允许长期2.4A运行的证明。

### 布局要求

- 芯片裸露焊盘下铺完整散热铜并布置过孔阵列；
- VM与PGND回路尽可能短；
- 每颗芯片旁放100nF陶瓷＋1µF/4.7µF陶瓷，并在两路驱动附近放置低ESR大容量电解/固态电容；
- 电机输出端预留RC吸收或TVS焊盘，最终参数通过示波器测量尖峰后确定；
- nFAULT、IPROPI各自引到FPGA，并保留测试点；
- IN1/IN2或PH/EN相关使能引脚必须有硬件下拉，保证FPGA未配置时电机不转。

### 不推荐TB6612FNG

TB6612FNG每路平均电流能力不足以稳妥覆盖MG513启动、冲击与接近堵转工况。其3.2A是峰值概念，不能等价于3.2A堵转持续承受能力。

---

## 3.4 两路步进电机驱动

### 首选：TMC2209-LA-T ×2；成本/易焊备选：DRV8825PWPR ×2

| 项目 | TMC2209-LA-T | DRV8825PWPR |
|---|---|---|
| 立创编号 | **C2150710** | **C81582** |
| 封装 | QFN-28-EP 5×5mm | HTSSOP-28-EP |
| VM范围 | 4.75~29V | 8.2~45V |
| 输出能力 | 2A级，双H桥 | 2.5A级，双H桥 |
| 特点 | StealthChop2静音、UART配置、运行平顺 | STEP/DIR简单、资料成熟、手工调试容易 |
| 检索库存 | 约12K+ | 约17K+ |
| 检索单价 | 1+约¥16.79；10+约¥15.01 | 1+约¥14.59；10+约¥12.72 |

**最终建议：**如果两只42步进电机用于云台、升降等需要安静和平顺的机构，选TMC2209，单颗仅比DRV8825贵约2元，综合性价比更高；如果团队更熟悉传统STEP/DIR、希望HTSSOP更易焊接和示波器调试，则选DRV8825。两者都必须按1.5A/相实测温升，不能把芯片峰值能力当作连续能力。LV8729虽适合此电流档，但立创自营页面已停售，不作为新设计首选。

### 重要注意事项

- 必须实测两台电机每相绕组电阻；
- 使用低温漂电流采样电阻，功率和脉冲能力留足余量；
- 1.5A/相时芯片和PCB会明显发热，必须使用裸露焊盘、散热过孔和较大铜面；
- 预留风扇接口或小散热片安装空间；
- VM旁陶瓷电容和大电解必须靠近驱动器，长线供电尤其要防LC尖峰；
- nSLEEP/nRESET默认拉到安全状态；
- 步进电机停止保持会持续耗电发热，软件应支持空闲降流或关闭保持。

### 是否一定要焊两颗DRV8825

若两只步进电机不是第一版机器人必需功能，建议：

- PCB保留DRV8825完整焊盘、端子和控制接口；
- 第一批只焊一颗或不焊；
- 先完成底盘、FPGA、Lichee Pi和直流电机的供电验证。

这样能降低首板BOM成本约¥25~30，并减少初期排查变量。

---

## 3.5 3.3V传感器支路

传感器预计电流不大，但考虑两个编码器、IMU、ToF及扩展，建议设计为3.3V/1A能力。

### 推荐方案

从其中一路稳定5V经独立低噪声稳压得到3.3V：

- 若实测总电流小于200mA：可选低噪声LDO，简单且干净；
- 若希望预留到0.5~1A：优先使用1A同步降压器，再在IMU电源前增加磁珠＋局部低噪声LDO/RC滤波。

不建议直接用AMS1117-3.3承担0.5A：从5V降到3.3V时理论发热约0.85W，且噪声和瞬态性能一般。

建议分网：

- `3V3_SENSOR`：编码器、ToF模块；
- `3V3_IMU`：由3V3_SENSOR经磁珠/滤波后供IMU；
- 每个外接传感器接口旁放100nF，适当增加1~10µF。

模块输入电压必须按购买的成品模块核实，不能把VL53L1X裸芯片规格与转接板输入规格混用。

---

## 4. 输入、保护和安全器件建议

## 4.1 电池输入接口与保险

- 电池接口优先使用板外短线XT60，或额定电流足够的高电流端子；普通2.54mm排针不可作为主动力入口。
- 主保险丝建议采用可更换汽车片式保险丝座或板外保险丝，首版额定值不要仅凭“20A布线目标”直接决定，应在实测整车峰值和线材能力后选定。
- 两类电机支路建议分别设置保险/电子保护，计算板5V支路独立保护。

## 4.2 防反接

首选P沟道MOS高边防反接或专用理想二极管控制器＋N沟道MOS。由于可能存在十几安培瞬态，MOSFET应满足：

- VDS至少30V，优先40V；
- 低RDS(on)，在实际VGS下给出参数；
- SO-8/PowerPAK/LFPAK等可散热封装；
- 按20A短时电流核算导通损耗与安全工作区。

不建议主输入串普通肖特基二极管，压降和发热较大。

## 4.3 TVS和母线电容

- 3S电池母线TVS建议从 **SMBJ15A** 档位开始评估，而不是直接采用5V TVS；必须结合实测回生尖峰确认其反向工作电压和钳位电压。
- 若尖峰钳位后仍可能超过降压器28V上限，需要加强TVS、吸收网络或分隔输入滤波，不能只依赖芯片绝对最大值。
- 输入端建议至少预留：100nF陶瓷、1µF陶瓷、10~22µF高压陶瓷，以及470~1000µF/25V低ESR电解或固态电容焊位。
- 大电容最终容量需结合线长、电机换向和回生波形确定。

## 4.4 急停

急停不要让小型按钮直接承担全部动力电流。推荐：

- 急停按钮控制额定合适的直流接触器/大电流高边开关；
- 硬件同时拉低所有DRV8874与DRV8825的使能/睡眠脚；
- 计算板和传感器供电尽量保留；
- FPGA能够读取急停状态并锁存故障；
- 断电并不等于立即制动，必须实测停车距离。

---

## 5. 推荐BOM主表

以下是“关键器件级BOM”，阻容、电感、MOS、端子需在完成原理图计算和封装确认后补全。

| 模块 | 推荐型号 | 立创编号 | 数量 | 检索小批量价格 | 备注 |
|---|---|---:|---:|---:|---|
| 5V同步降压 | SY8368AQQC | C207642 | 2 | ¥5.10/颗 | FPGA与Lichee Pi各一路 |
| USB-C源端控制 | TPS25810RVCR | C473913 | 2 | ¥4.28/颗 | 3A宣告、受控VBUS |
| USB-C母座 | USB4105-GF-A-120 | C5184243 | 2 | ¥5.62/颗 | 定板前核对3A额定与机械封装 |
| 直流电机驱动 | DRV8874PWPR | C1855818 | 2 | ¥6.30/颗 | 每台MG513一颗 |
| 步进电机驱动（首选） | TMC2209-LA-T | C2150710 | 2 | ¥16.79/颗 | 静音、UART；1.5A/相需散热 |
| 步进电机驱动（备选） | DRV8825PWPR | C81582 | 2 | ¥14.59/颗 | 易调试；与TMC2209二选一 |
| 输入TVS参考 | SMBJ15A | 下单前按品牌筛选 | 1~2 | 通常低价 | 根据尖峰实测定最终型号 |
| 3.3V稳压 | 1A同步Buck或低噪声LDO | 待结合实测电流确定 | 1 | — | 不建议AMS1117承担0.5A |
| 电流采样电阻 | 低温漂、1%或更高精度 | 按计算选 | 若干 | — | DRV8825/监测用途 |
| 大容量电容 | 25V低ESR 470~1000µF | 按尺寸筛选 | 2~4 | — | 电机区和输入区 |
| 电机端子 | 5.08mm/7.62mm大电流端子 | 按电流筛选 | 4 | — | 2路DC＋2路步进 |

### 关键芯片小批量成本估算

- 不装步进驱动：约 `2×5.10 + 2×4.28 + 2×5.62 + 2×6.30 ≈ ¥42.6`；
- 加装两颗DRV8825：再加约 `2×14.59 ≈ ¥29.2`；
- 关键芯片合计约 **¥71.8**。

以上不含电感、功率电容、端子、MOS、保险、PCB和SMT费用。完整单板小批量物料成本预计会显著高于关键芯片合计，尤其是大电流电感、连接器和低ESR电容。

---

## 6. PCB分区和布线建议

建议按以下顺序从板的一端排到另一端：

```text
电池入口/保险/防反接/TVS
        ↓
动力母线与大电容
  ├─ DRV8874区 → DC电机端子
  ├─ DRV8825区 → 步进电机端子
  └─ 两个独立Buck区
          ↓
    两个TPS25810＋USB-C口
          ↓
    3.3V传感器与逻辑接口区
```

具体规则：

1. 电机功率地、降压功率地与传感器地采用分区回流，在电池入口/母线电容附近形成明确汇合点。
2. 不要切割控制信号下方的参考地平面。
3. 每个开关电源的高di/dt热环路必须极小，不要让SW节点铺铜过大。
4. 电机输出、SW节点远离IMU、编码器和USB-C CC走线。
5. 驱动器裸露焊盘下使用密集散热过孔连接内层/底层铜。
6. 大电流铜皮避免“细颈”；连接器焊盘到铜皮的过渡也要按电流核算。
7. 每路电源放置输入、输出和使能测试点；DRV8874放置IPROPI和nFAULT测试点。
8. 所有外接控制输入增加串联小电阻焊位，便于抑制振铃和调试。
9. 编码器接口建议增加施密特缓冲/RC可选焊盘和ESD保护，但滤波时间不能达到按键去抖级别。
10. FPGA到电机驱动的安全禁止信号应有硬件默认下拉，并尽可能能够同时禁止全部驱动。

---

## 7. 第一版建议的可制造配置

为了降低一次性失败风险，建议首板采用以下装配策略：

### 必装

- 输入保护与母线；
- SY8368A ×2；
- TPS25810 ×2；
- USB-C ×2；
- DRV8874 ×2；
- 3.3V传感器支路；
- 电压、电流、故障测试点；
- 急停/总使能接口。

### 可选焊

- DRV8825 ×2及其采样电阻；
- 电机端RC吸收；
- 额外母线电容；
- 编码器施密特缓冲；
- 风扇接口和温度传感器。

### 强烈建议分阶段上电

1. 不焊主芯片，先检查电池输入无短路；
2. 只焊第一路5V，使用电子负载验证0.5A、1A、2A、3A及热稳定；
3. 验证TPS25810和USB-C插拔、短路、过流和断电放电；
4. 重复验证第二路5V；
5. 接Lichee Pi，测启动、CPU负载和USB外设情况下板端电压；
6. 在确认ACG720 Type-C供电路径后再接FPGA；
7. 单独焊接并验证一颗DRV8874，先用小电机/限流电源测试；
8. 再接MG513，测试空载、启动、换向、接近堵转和温升；
9. 最后验证第二路直流电机与可选步进驱动；
10. 做全负载、电池低电压、电机换向和急停测试。

---

## 8. 投板前必须确认的事项

- [ ] 3S电池欠压策略已确定：优先单节监测/BMS；至少设置整包约9.6~10.2V软关机区间，并结合电芯规格、负载压降和去抖时间实测；
- [ ] ACG720的Type-C口确认可给整板供5V，且允许电流满足实测峰值；
- [ ] Lichee Pi 4A使用的具体Type-C口和5V/3A要求确认；
- [ ] 两块计算板均实测启动、稳定和峰值电流；
- [ ] MG513编码器是13PPR霍尔还是500PPR GMR，线序和3.3V输出电平确认；
- [ ] 两台MG513启动、正常负载和接近堵转电流实测；
- [ ] 两只步进电机绕组电阻实测；
- [ ] SY8368A原厂参考电路、电感值和电流能力完成计算；
- [ ] 5V端电压根据线缆压降决定是否设置约5.1V；确认Type-C接口端全工况不超过5.5V；
- [ ] 每个USB口限流阈值、浪涌电容和软启动已验证，建议阈值约3.3~3.6A而非刚好3A，避免启动误触发；
- [ ] Type-C所有VBUS/GND触点并联，走线、过孔、插座按至少3A核算；CC和外壳ESD/接地策略已确定；
- [ ] TPS25810配置、电流宣告和USB-C连接方式按数据手册复核；
- [ ] USB4105插座3A额定及封装尺寸复核；
- [ ] DRV8874限流参数按数据手册重新计算，IPROPI/VREF采用Kelvin布局并避开OUT/SW噪声；
- [ ] 电机端子旁预留共模磁珠/串联电感和RC吸收焊盘；
- [ ] DRV8825 VREF和采样电阻按1.5A/相重新计算；
- [ ] 急停硬件能禁止所有电机驱动；
- [ ] ERC/DRC通过；
- [ ] 大电流网络完成线宽、铜厚、过孔、温升和连接器能力核算；
- [ ] 首板准备限流电源、电子负载、示波器和热像仪/测温设备。

## 9. 最终推荐版本

### 方案A：最低BOM、仍保持可靠（推荐先评估）

- `SY8368AQQC ×1`：做中央5V/8A同步降压；
- 每个USB-C口各一颗受控限流/反灌阻断eFuse或load switch；
- 每个USB-C口各一套CC检测/源端控制，检测到对端Rd后才接通VBUS；
- `USB4105-GF-A-120 ×2`；
- `DRV8874PWPR ×2`；
- 步进部分在`TMC2209-LA-T ×2`与`DRV8825PWPR ×2`中二选一；
- 独立3.3V/1A传感器电源；
- 主输入保险＋防反接MOS＋合适TVS＋足量25V母线电容。

该方案在两个Type-C端口仍保持独立过流、短路和反灌保护的前提下，比两颗5V Buck更省成本、更省板面积。缺点是两块计算板共用中央5V降压，若一口严重短路而eFuse故障或布局不当，可能影响另一口；因此中央5V必须选真正连续≥8A、28V级输入、具备良好热设计的同步Buck，并在每口加独立保护。

### 方案B：故障和噪声隔离优先

- `SY8368AQQC ×2`：ACG720和Lichee Pi各一颗；
- `TPS25810RVCR ×2`：每口完成CC检测、3A宣告和受控VBUS；
- `USB4105-GF-A-120 ×2`；
- `DRV8874PWPR ×2`；
- `TMC2209-LA-T ×2`（静音优先）或`DRV8825PWPR ×2`（易调试优先）；
- 独立3.3V/1A传感器电源。

方案B成本略高，但调试最直观：Lichee Pi负载突变、电机噪声或单路故障对另一块计算板的影响最小。若FPGA和Lichee Pi同时承担关键任务，建议采用方案B。

### USB-C源端的强制要求

- 不要把“Rp电阻＋永远带电的VBUS”当作正式方案；
- USB-C源端应通过CC1/CC2检测到对端Rd后再接通VBUS；
- 3A广告通常为CC1、CC2各约10kΩ到5V（最终按控制器数据手册配置）；
- 受电板必须确认是sink，避免两端都是source时互相顶电；
- 各口都要有VBUS限流、软启动、短路保护和反向电流阻断；
- 测试时核对插拔、短路、断电和调试线缆接入时的反灌行为。

### 回生与母线保护

满电12.6V时，电机急减速可能把能量回灌到VBAT，使母线高于正常电池电压。TVS只适合吞瞬态，不能替代持续制动能量处理。必须：

- 通过速度斜坡限制制动和换向；
- 在动力母线附近放置足量低ESR电容；
- 示波器实测急停、急减速和换向尖峰；
- 若回生明显，增加制动钳位/耗能电阻方案，或确认电池能安全吸收回生电流；
- 不能仅凭SMBJ TVS就宣称母线长期安全。

该配置兼顾了成本、现货、调试难度和保护能力。真正决定首板能否稳定工作的重点，不只是芯片型号，而是：**ACG720 Type-C供电确认、USB-C源端CC握手、5V降压的连续电流与热设计、DRV8874/步进芯片裸露焊盘散热、大电流回流路径、母线回生与急停设计。**

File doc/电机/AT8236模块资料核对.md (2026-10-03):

# AT8236 双路模块资料核对

核对日期：2026-10-02。资料：[用户提供的合并长图](合并长图_1-9.png)、杭州中科微 AT8236-S409-V1.1 芯片手册，以及当前 `pcb/power/kicad/ProPrj_power_2026-10-02` 工程。本记录区分卖家模块标称、芯片推荐条件与本板实际连接，不把图片当作模块温升或限流的实测证明。

## 1. 结论

该资料对应 **MD-AT8236 V1.0 类双路直流有刷电机模块**：每块有两颗 AT8236，每颗一路 H 桥，合计能独立控制两台直流电机。资料中的 TB6612 内容属于另一款产品，不能混用其 PWMA/PWMB、STBY 和 VCC 规格。

3S 电池正常约 9–12.6 V 落在模块标称 VM 范围内，FPGA 3.3 V 控制信号也能满足 AT8236 输入条件。对项目 MG513X 单台额定 0.36 A，模块具有选型基础；但单台 3.2 A 堵转超过模块标称 3 A 持续值，**不能据“6 A 峰值”宣称可持续堵转**，启动、保护阈值和散热仍需实测。

当前原理图使用每块模块的 A 通道，A 输入与 A 输出的网络命名相符，未用 B 输出可以保持不连接。**PCB 的 J6/J8 排针顺序却与模块相反，且排距没有匹配模块尺寸。当前布局不能直接插入模块上电。**

## 2. 参数核对

| 项目 | 用户资料中的 AT8236 模块 | 核对结果及项目边界 |
| --- | --- | --- |
| 通道数 | 两路 | 每颗 AT8236 一路 H 桥；一块双路模块理论上足够驱动两台底盘电机，当前工程用了两块、各用 A 通道 |
| VM | 5–17 V | 3S 正常电压可覆盖；原厂芯片推荐 5.5–36 V，因此不把模块标称 5 V 下限当作全工况保证，也不能把裸芯片 36 V 上限套到成品模块 |
| 每路电流 | 3 A 额定、6 A 峰值 | 原厂手册推荐条件表为连续 3 A、峰值 4.5 A，绝对极限表为 ±6 A；首页又写 4 A 连续/6 A 峰值，资料本身存在口径差异。设计以推荐条件表和模块实测为依据 |
| IN 输入电压 | 0–5.25 V | 芯片 VIH 最小 1.5 V、VIL 最大 0.7 V；3.3 V 控制高低电平相容 |
| PWM 输入频率 | 0–100 kHz | 100 kHz 是上限；现有 FPGA 文档中的 20 kHz 位于范围内，但输出接法需要适配 AT8236 |
| VCC | 0–4 V，参考电压输入 | **是输入，不能给编码器提供 3.3 V。** 外部 3.3 V 在图示范围内；不得套用 TB6612 的 5 V 逻辑供电接法 |
| 保护 | 过流、短路、欠压、过温 | 不能推断具备 3S 电池保护、系统故障锁存或可供 FPGA 读取的故障输出；资料接口没有 nFAULT |
| 外形 | 参数表 23 × 18.5 mm；尺寸图 23 × 18 mm | 图中两个尺寸口径有 0.5 mm 差异；没有孔中心距、孔径、针长和电容高度，不能据此外形生成已验证插接封装 |
| 重量、温度 | 3.5 g（含排针）、−40～85°C | 均为资料标称；工作温度不是模块在 3 A 时的允许温升证明 |

芯片参数依据：[杭州中科微 AT8236-S409-V1.1 手册，第 1、3、4 页（原厂文件镜像）](https://atta.szlcsc.com/upload/public/pdf/source/20210923/1552D95CBAF8BE780D06AE79E7783380.pdf)。特别是 6 A 绝对极限不能当作持续输出能力。

## 3. 模块实物接口与 KiCad 编号

以长图中电容朝上、`MD-AT8236 V1.0` 字样可正常阅读的那张接口照片为准，从上到下：

| 位置 | 左排功能 | 右排功能 |
| --- | --- | --- |
| 1 | AOUT2 | GND |
| 2 | AOUT1 | VM |
| 3 | BIN1 | VCC |
| 4 | BIN2 | AIN2 |
| 5 | VCC | AIN1 |
| 6 | VM | BOUT1 |
| 7 | GND | BOUT2 |

左排 AOUT 与右排 AIN 属于同一 A 通道；左排 BIN 与右排 BOUT 属于同一 B 通道。它们交叉分布在两排上是模块布局，不代表原理图把 A/B 接反。

当前 KiCad 采用两排分别编号的方法，而非模块统一的 1–14 编号。保留当前逻辑网络时，应使用下表：

| KiCad 焊盘号 | J5/J7 左排功能 | J6/J8 右排功能 |
| --- | --- | --- |
| 1 | AOUT2 | BOUT2，当前 NC |
| 2 | AOUT1 | BOUT1，当前 NC |
| 3 | BIN1 | AIN1 |
| 4 | BIN2 | AIN2 |
| 5 | VCC | VCC |
| 6 | VM | VM |
| 7 | GND | GND |

**两排的物理编号必须反向排列。** 当左排沿某方向为 1→7 时，对面的右排沿同方向必须为 7→1，才能对应接口照片。

### 当前连接的正确部分

- 左电机：`J1.1/2 → LAIN1/2 → J6.3/4`；`J5.2/1 → LAOUT1/2 → J3.6/1`。
- 右电机：`J2.5/6 → RAIN1/2 → J8.3/4`；`J7.2/1 → RAOUT1/2 → J4.6/1`。
- J5/J7 的 3、4 脚是 B 通道控制；J6/J8 的 1、2 脚是未接出的 B 通道输出。未用通道应保持 IN1=IN2=0，NC 输出不能拿来并联增加电流。
- 四排的 5 脚都接 `/3.3V`，6 脚接 `/VM`，7 脚接 GND。按接口资料，VCC 均应作为外部参考输入处理；两侧 VCC 是否在模块内部相连仍需实物导通确认。

### 当前 PCB 必须修改的部分

原生 PCB API 读取结果：四排均为 0°，每排焊盘 1→7 的 X 坐标都递增，步距为 2.54 mm。这与上述反向编号要求冲突。沿 J5/J7 的 1→7 方向观察 J6/J8：

| 物理位置 | 模块右排要求 | 当前 PCB 连接 |
| --- | --- | --- |
| 1 | GND | NC |
| 2 | VM | NC |
| 3 | VCC | AIN1 控制网络 |
| 4 | AIN2 | AIN2 控制网络 |
| 5 | AIN1 | `/3.3V` |
| 6 | BOUT1 | `/VM` |
| 7 | BOUT2 | GND |

如果按图直接插接，部分桥输出会接到 VM/GND，控制脚也会错位，有损坏风险。改版时需要将 **J6/J8 绕各自排针中心旋转 180°并重布受影响走线**，或创建包含两排且编号正确的整体模块封装；不能只翻转丝印。

本板 J5–J6 排中心距为 **23.0005 mm**，J7–J8 为 **23.1275 mm**。资料的 23 mm 是模块外形长边，孔中心位于板内，不能拿外形尺寸直接当排中心距；两组现值也不一致。需测量实际模块的两排孔中心距，再统一修改。资料没有给出该数值，本次未把推测值写入封装。

本次重新导出当前原理图网表，核对 J1–J8 共 56 个引脚与 PCB 网络全部一致。这个检查证明文件之间一致，**不能消除模块物理接法错误**。坐标和网络证据见 [接口核对 JSON](../../pcb/power/kicad/review/at8236-interface-audit.json)。

## 4. VCC、限流与 3.3 V 电源

裸芯片没有独立的逻辑 VCC 电源脚，具有 VREF 电流参考脚。模块将 VCC 标为参考输入；它是否直接连接两颗芯片的 VREF、经过分压还是另有电路，应检查模块背面线路或索取原理图。

若模块 VCC 直接进入 VREF 且 ISEN 使用检测电阻，则原厂关系为 `I_TRIP = VREF / (10 × R_ISEN)`。因此 **VCC=3.3 V 不等于限流 3 A**，例如 `R_ISEN=0.1 Ω` 时对应约 3.3 A。长图不同产品照片可见 R005 和 R015 等不同标识，不能仅凭照片确定实物检测阻值和最终限流。需核对实际阻值、连接方式及保护电流，再决定 VCC 接固定 3.3 V 还是专门的参考电路。[原厂手册第 6 页](https://atta.szlcsc.com/upload/public/pdf/source/20210923/1552D95CBAF8BE780D06AE79E7783380.pdf)

当前 `/3.3V` 网络仍没有明确板上电源。既然 VCC 已确认是输入，驱动模块不能被列为该网络的供电来源。应明确由电源板稳压器或经过能力核实的 FPGA 电源提供，并同时覆盖编码器、传感器和参考输入负载。

## 5. 控制逻辑与 FPGA 适配

资料图的真值表如下，Z 表示高阻：

| IN1 | IN2 | OUT1 | OUT2 | 状态 |
| --- | --- | --- | --- | --- |
| 0 | 0 | Z | Z | 滑行；持续低电平后休眠 |
| 1 | 0 | H | L | 正向驱动 |
| 0 | 1 | L | H | 反向驱动 |
| 1 | 1 | L | L | 制动 |

先按资料中的快衰减接法核对输出：正向 `IN1=PWM、IN2=0`；反向 `IN1=0、IN2=PWM`；禁止/复位时两输入均为 0。电机实际“车身向前”仍由线序、安装方向和编码器正方向共同确定。

现有 FPGA 驱动文档描述的是 **TB6612 的 IN1/IN2、独立 PWM 与 STBY**。AT8236 这款模块只有每通道两个 IN，不能只把原 TB6612 的方向 IN 接过来而悬空原 PWM，这会失去调速；也不能把原 STBY 当作本模块已有的独立使能。需要用 PWM 与方向/禁止状态形成两路 AT8236 IN 输出，并检查引脚约束和复位默认状态。该项是驱动接口适配工作，本次资料核对未改 RTL。

`00` 是滑行，不保证立即停止。停止距离、软件制动和硬件急停需要分别验证；参考输入也不能被直接当作已验证的急停使能。

## 6. 进入上电验证前

1. 按实物修正 J6/J8 排列与两组排距，核对模块插入方向及电容/排母高度。
2. 明确 3.3 V 来源；确认 VCC→VREF 路径、检测电阻、限流和模块输入电容耐压。
3. 适配 FPGA 的两个 IN 输出；检查复位、下载、零命令和通信中断时保持禁止。
4. 完成电源保护与现有 PCB 断连修复后，用限流电源分阶段检查空载、启动、换向、接近堵转、温升和母线尖峰。模块过流保护不能代替电池保护或系统故障锁存。

本次确认的是资料参数、接口对应与现有 PCB 差异，尚没有模块实物电流、温升或排距的测试结果。

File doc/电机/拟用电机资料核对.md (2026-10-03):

# 拟用电机资料核对

整理日期：2026-09-23。依据用户提供的两张实物照片、现有项目文档和下列资料链接。照片铭牌是这两只实物的识别依据；同系列网页参数不能替代实物参数或厂家针对该配置的规格书。

> **2026-10-02 驱动更新：**当前选用双路 AT8236 模块，用户已补充 [资料长图](合并长图_1-9.png)。模块参数、VCC 输入、两排线序及 PCB 排列问题见 [AT8236 模块资料核对](AT8236模块资料核对.md)。以下电机铭牌与系列手册数据不变；DRV8874 保留为历史选型比较。

## 1. WHEELTEC MG513XP28_12V：底盘直流减速电机

照片可直接确认：品牌 WHEELTEC、型号 `MG513XP28_12V`、标记 `F01070199`。这是带轮的直流有刷减速电机，拟用于双轮差速底盘。型号中的 `12V` 与 `P28` 分别与现有项目文档中的 12 V、1:28 减速比一致；`F01070199` 的含义未查到可靠定义。

新增的 WHEELTEC 产品手册在 **MG513X** 行明确列出 1:28、12 V、额定电流 0.36 A、堵转电流 3.2 A、减速后空载转速 370 ± 12 rpm、额定转速 300 ± 12 rpm、额定扭矩 1.02 kg·cm。这与照片型号及项目文档相符，但手册表格使用系列名 MG513X，没有单列 `MG513XP28_12V` 的批次编号；仍需用实物确认编码器版本和负载电流。切勿把同表中 **MG513XL 的 1 A 额定、6 A 堵转**误用到 MG513X。

WHEELTEC 新版产品手册在 MG513X 编码器表中列出 13 PPR 霍尔和 500 PPR GMR 两种 AB 相编码器，均可用 3.3–5 V 供电；其接线图显示两种版本的六针线序不同。厂家编写的[直流电机开发手册镜像](https://studylib.net/doc/28303424/wheeltec-%E7%9B%B4%E6%B5%81%E7%94%B5%E6%9C%BA%E5%BC%80%E5%8F%91%E6%89%8B%E5%86%8C-2025.10.20)还说明 AB 输出高电平随编码器供电变化。照片能看到编码器板和排线，但无法可靠辨明版本。接入 ACG720 的 3.3 V IO 前，务必先确认实物的编码器类型、电源极性、排线线序和输出电平，不能照搬另一版本的接线图。

若实物确为**电机轴每相 13 个周期、齿轮比 28:1**，则输出轴每转理论计数为：A 相单沿 `13×28=364`，A 相双沿 `728`，AB 四倍频 `1456`。若为 500 PPR GMR，则相应四倍频理论值为 `500×28×4=56000`。这些都是条件计算，不是已实测分辨率。左右轮应分别手转输出轴多圈，用 FPGA 计数并确定正方向。

驱动方案：一台可逆直流电机需要一路 H 桥。当前 AT8236 双路模块每块有两路，工程使用两块、各自 A 通道驱动一台 MG513；3S 正常电压及 FPGA 3.3 V IN 电平具备适配基础。模块资料标称每路 3 A 持续/6 A 峰值，MG513X 的 3.2 A 堵转不能按峰值能力当作允许持续工况，需核实模块限流、启动和温升。VCC 为外部参考输入，不能给编码器供电；PCB 对排顺序和排距仍需修正，详见上述核对记录。

历史比较：[TI DRV8874](https://www.ti.com/product/DRV8874) 每片一路全桥，所列 6 A 为峰值；原 TB6612FNG [数据手册](https://toshiba.semicon-storage.com/info/TB6612FNG_datasheet_en_20141001.pdf?did=10660&prodName=TB6612FNG)给出每路 1.2 A 平均、3.2 A 峰值。这些器件的控制方式、电流采样和故障引脚不能直接套用到当前 AT8236 模块。

## 2. 普菲德 42BYGH34-401A：两相四线步进电机

第二张照片铭牌可直接确认：型号 `42BYGH34-401A`，转矩 `0.28 N·m`，步距角 `1.8°`，电流 `1.5 A`，品牌字样为“普菲德”。电机为两相四线，铭牌接线为：

| 颜色 | 铭牌端子 | 绕组 |
| --- | --- | --- |
| 黑 | A+ | A 相 |
| 绿 | A− | A 相 |
| 红 | B+ | B 相 |
| 蓝 | B− | B 相 |

`1.8°` 对应一圈 `360/1.8=200` 个整步。`0.28 N·m` 通常按保持转矩理解，不能推断为任意转速下的输出转矩。铭牌未标绕组电阻、电感、允许温升、转矩转速曲线或轴/安装尺寸；网上同型号存在参数不一致的变体，机械尺寸应直接测量或向卖方索取该批次图纸。

该电机需要一路**两相、双 H 桥、恒流斩波**步进驱动器。例子：[TI DRV8825](https://www.ti.com/product/DRV8825) 支持 STEP/DIR、可设相电流和最高 1/32 细分；[东芝 TB6600HG](https://toshiba.semicon-storage.com/ap-en/semiconductor/product/motor-driver-ics/stepping-motor-driver-ics/detail.TB6600HG.html)也是两相步进驱动芯片。选择的是具体驱动**模块**时，还需核对模块的电流设定方式、散热、输入电平和供电范围。铭牌的 `1.5 A` 通常指每相额定电流，但仍宜向卖方确认；不能把驱动器电源电压直接当作绕组额定电压，也不能把该电机接到单路 DRV8874 直流电机模块上。

接线前断电，用万用表确认黑—绿为一组绕组、红—蓝为另一组；若实际线束经过转接板或重新压线，应以导通实测为准。步进电机本体照片未显示编码器，若用它承担闭环定位，需另配编码器或回零/限位检测。用于云台、升降或旋转执行机构时，还需按实际传动比和负载测试运行转矩、加减速和失步情况。

## 3. 这两种电机在机器人中的分工

- MG513XP28_12V：适合作为左右驱动轮，结合 AB 编码器完成轮速闭环和里程计。
- 42BYGH34-401A：适合作为独立的定位执行轴（例如云台、升降、机械机构），需要单独的步进驱动和限位/回零方案。它与轮速 PI 的电机接口不同。
- 若计划把两只步进电机也纳入整车，需在电源预算中增加驱动器与相电流引起的持续功耗，并明确它们各自驱动的机构。

## 4. 上板前需要实测或索取的资料

1. MG513 左右两只电机的编码器版本、排线线序、每输出轴转实测计数和正方向。
2. 按已取得的 MG513X 系列手册核对实物安装尺寸，并实测两只电机的启动、额定附近和接近堵转时的电流；不要长时间人为堵转。
3. 两只步进电机的绕组电阻、轴径/轴长、安装孔距，以及所选驱动模块的相电流设置和 3.3 V 控制信号兼容性。
4. 给驱动和 FPGA 分支供电后，测启动、换向、急停和接近堵转时的电压跌落、温升与停车距离。

## 资料入口与可信度

- [WHEELTEC 官网](https://www.wheeltec.net/)及其[MG513 系列应用产品手册](https://www.wheeltec.net/R550.pdf)：厂家来源，但 R550 的电机/编码器配置不代表本照片中的 XP28 版本。
- 本地另有 WHEELTEC 2026-07-28 版《轮趣直流有刷电机产品说明手册（尺寸、参数、线序）》第 7–9 页，是本节 MG513X 系列参数和两种线序的主要依据。其资料包版权声明限制未经许可传播，故不随公开仓库上传原件。
- [WHEELTEC 编写的直流电机开发手册镜像](https://studylib.net/doc/28303424/wheeltec-%E7%9B%B4%E6%B5%81%E7%94%B5%E6%9C%BA%E5%BC%80%E5%8F%91%E6%89%8B%E5%86%8C-2025.10.20)：解释编码器与计数，镜像站并非厂家官网。
- [TI DRV8874 产品页与数据手册](https://www.ti.com/product/DRV8874)、[TI DRV8825 产品页与数据手册](https://www.ti.com/product/DRV8825)、[东芝 TB6600HG 产品页](https://toshiba.semicon-storage.com/ap-en/semiconductor/product/motor-driver-ics/stepping-motor-driver-ics/detail.TB6600HG.html)、[东芝 TB6612FNG 数据手册](https://toshiba.semicon-storage.com/info/TB6612FNG_datasheet_en_20141001.pdf?did=10660&prodName=TB6612FNG)：驱动芯片厂家一手资料。
- 未找到可核对为“普菲德 42BYGH34-401A 本批次”的官方规格书；本文步进电机的确定参数取自实物铭牌。

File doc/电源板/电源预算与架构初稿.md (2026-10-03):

# 小车电源预算与电源板架构初稿

> **2026-10-02 最新方案补充：**用户确认使用其他品牌的**双路 AT8236 模块**；下文 DRV8874/IPROPI 等是历史预算假设，不适用于当前驱动方案。当前 KiCad 工程位于 `pcb/power/kicad/`，已画有两路 MP2236 5V 输出，文中的旧 9V 支路描述不适用于这套工程。当前接口、3.3V 来源、保护与 PCB 问题见[电源板审查与修改清单](../../pcb/power/kicad/review/电源板审查与修改清单.md)，本预算不能直接作为当前可投板/可采购依据。

> **AT8236 资料已核对：**模块标称 VM 5–17V、每路 3A/6A 峰值，VCC 是 0–4V 外部参考输入，不能供给本板 3.3V。工程各用一块模块的 A 通道；当前 PCB 对排排列与模块相反，排距、限流和散热仍待修正/实测。控制输出还需从现有 FPGA 文档的 TB6612 接口适配。详见 [AT8236 模块资料核对](../电机/AT8236模块资料核对.md)。

> 状态：首版设计预算，尚非最终器件选型或已实测功耗。整理日期：2026-09-23。
> 本文按一块 ACG720、一块 OV5640 摄像头、一块 Lichee Pi 4A、两台 WHEELTEC MG513XP28_12V、两台普菲德 42BYGH34-401A、一块 ICM-42688-P 模块和**一块** VL53L1X 模块计算。其他资料中提到的三块 VL53L1X 不计入本版。
> 2026-09-24 原理图 Rev B 已改为板载 **DRV8874 ×2**，每台 MG513 独占一片 H 桥；不再使用外接 TB6612 或专用 10 V 电机降压支路。
> 本版供电目标改为 **ACG720 与 Lichee Pi 4A 分别通过各自 USB Type-C 口取 5 V**。这是电源预算与待实施方案，**现有 `pcb/power/power.kicad_sch` 仍为 ACG720 9 V 原电源口、Lichee Pi 4A USB-C 的旧拓扑，尚未同步修改原理图/PCB**。ACG720 的 Type-C 整板供电能力及接口位置待原厂原理图和实物确认。

## 1. 电池输入边界

现有电池照片铭牌为 **3S Li-Po，11.1 V 标称、3600 mAh、35C**。满电约 12.6 V；标称能量 `11.1 V × 3.6 Ah ≈ 40 Wh`。`35 × 3.6 Ah = 126 A` 只是铭牌倍率的算术结果，不代表老电池当前安全可用电流，更不代表小车需要这么大电流。

电源板输入器件应覆盖满电电压、运行过程的电压下跌以及电机引起的瞬态；首版以 3S 电池为唯一电源，充电仍由外部合规的 3S 平衡充电器完成。老电池使用前须检查鼓包、外皮和线束损坏、各单体电压及负载下压降。若状态不明，不以 35C 标称值代替检查。

应设计单体电压监测或使用可靠的 3S 电池保护/监测模块。仅监测总电压不能发现其中一节电芯异常偏低。欠压应先停止电机并提示，再给 Lichee Pi 4A 留出正常关机时间；具体告警、切断阈值需结合电池规格、负载压降与实测设定，不把瞬间压降当作永久欠压。

## 2. 负载与支路预算

下表中“预留能力”是建议选择的供电级/布线能力，**不是设备已测得的工作电流**。电机支路的额定电流、堵转电流与持续可承受电流也不能混为一谈。

| 负载 | 电压与已知耗流 | 首版电源板预留 | 依据与待核对项 |
| --- | --- | --- | --- |
| MG513XP28_12V ×2 | 12 V 额定；单台额定 0.36 A、堵转 3.2 A。两台合计额定 0.72 A、12 V 下堵转约 6.4 A | 走受保护的电池动力母线；板载 DRV8874 ×2，每台单独限流并引出故障/电流反馈。初版 13 kΩ / 20 kΩ VREF 分压配 1.8 kΩ IPROPI 电阻，对应典型斩波阈值约 2.4 A/台，须实测验证 | WHEELTEC 本地产品手册 MG513X 表 2-1、TI DRV8874 数据手册；实物编码器版本、线序、电流波形和散热仍须确认 |
| 42BYGH34-401A ×2 | 铭牌 1.5 A，通常指每相电流；两相四线 | 两个独立恒流斩波步进驱动器，从电池动力母线供电；先按每路 3 A、两路合计 6 A 的输入布线能力预留 | 绕组电阻、驱动器效率及实际母线电流未测；1.5 A 相电流不能直接当作电池电流相加 |
| ACG720 ＋ OV5640 | 项目已有资料记载原电源口输入 6–12 V；**Type-C 5V3A**；配套 ACM5640 摄像头接口为 3.3 V | 目标为**独立 5 V / 3 A 预留降压级**，经独立、受保护的 USB-C 5 V 输出给已确认可供电的 ACG720 Type-C 口；实际对外宣告电流须与接口、线缆、源端控制器及板卡输入能力一致，未核实前不得按 4 A 或 3 A 直接接入 | 5 V / 4 A 仅为降压级待验证设计余量，不是板卡输入额定值；摄像头从板载接口取电并计入此支路；确认供电口、开关状态、VBUS 电源路径和启动/峰值功耗 |
| Lichee Pi 4A | Sipeed 官方 FAQ：USB-C 仅 5 V，至少 5 V / 2 A，建议 5 V / 3 A | 保留**独立 5 V / 4 A 降压级预留**，通过符合 USB-C 规范的 5 V / 3 A 源端及独立线缆向供电口输出 | 5 V / 4 A 是降压级余量，不表示 USB-C 可宣告 4 A；外接 USB、HDMI 和运算任务会改变耗流，重载时尤其要测板端电压与供电能力 |
| ICM-42688-P 模块 | 芯片 VDD/VDDIO 范围 1.71–3.6 V，六轴低噪声模式典型约 0.88 mA | 与编码器、测距模块共用独立低噪声 3.3 V / 0.5 A 支路 | 成品模块可能带 LDO 或电平转换，按实物模块输入标识接线；勿给裸芯片直接加 5 V |
| VL53L1X 模块 ×1 | 裸器件 AVDD 2.6–3.5 V，测距时平均约 16–18 mA，峰值可达 40 mA | 计入 3.3 V / 0.5 A 传感器支路；若为裸器件设计，按原厂建议配置 2.8 V 与 I/O 电平 | 成品模块的输入范围、电平转换与接口上拉须按实物确认；它是单点 ToF 测距器，不是 2D 扫描雷达 |
| MG513 编码器 ×2 | WHEELTEC 手册给出 3.3–5 V 供电，高电平随供电电压变化 | 建议验证后以 3.3 V 供电、接 FPGA 3.3 V IO；留滤波和测试点 | 霍尔版和 GMR 版 6 针线序不同，绝不能在未知类型时照搬接线 |

MG513X 原厂手册给出 1:28 减速比、12 V、0.36 A 额定、3.2 A 堵转、370 ± 12 rpm 空载、300 ± 12 rpm 额定，并列出 13 PPR 霍尔和 500 PPR GMR 两种编码器。**3.2 A 是堵转工况，不是允许持续运行的电流。** 当前原理图采用两颗 TI DRV8874，每台电机一路全桥；其 6 A 指芯片峰值能力，持续能力仍取决于散热和 PCB。初版电流斩波阈值约 2.4 A 并不等于允许持续运行在 2.4 A，保险丝也不能代替芯片限流。

步进驱动可评估 TI DRV8825 等双全桥、恒流器件，电流限制先依电机每相 1.5 A 铭牌设置，再按照模块散热和驱动器的电流定义实测。DRV8825 的 VM 工作范围为 8.2–45 V，可覆盖 3S 电池运行区间；具体模块的输入电容耐压、散热与瞬态仍须核对。**单路 DRV8874 不是一台两相步进电机的完整驱动器。**

步进电机的电池输入电流不能从“1.5 A × 4 相”直接得到。若停机保持时两相均为 1.5 A，单台电机绕组铜损上限示意为 `P ≈ 2 × (1.5 A)^2 × R相 = 4.5 R相 W`；两台相同电机约为 `9 R相 W`，另加驱动器损耗。只有测得绕组电阻、驱动方式和实际母线电流后，才能定下持续功率与保险丝。

## 3. 首版电源树

```text
3S Li-Po 9~12.6 V（低端设计边界与切断点待实测）
  └─ 电池连接器 → 主保险/过流保护 → 防反接 → 主开关/监测
       ├─ VBAT_MOTOR  → 板载 DRV8874 ×2 → MG513 ×2
       ├─ VBAT_STEPPER → 恒流步进驱动 ×2 → 步进电机 ×2
       ├─ BUCK_A 5 V / 4 A（预留）→ 独立保护＋合规 USB-C 源端
       │                           → ACG720 已确认的供电 Type-C 口 → OV5640
       ├─ BUCK_B 5 V / 4 A（预留）→ 独立保护＋5 V / 3 A USB-C 源端
       │                           → Lichee Pi 4A 供电 Type-C 口
       └─ 低噪声 3.3 V / 0.5 A → 编码器 ×2、ICM-42688-P、VL53L1X 模块
```

高电流电机不一定需要一条恒定 12 V 母线：直流电机可在 3S 电池动力母线上由合适的 H 桥和电流限制控制，步进驱动器也可由动力母线供电并用斩波限相电流，这样避免一只大功率 12 V 升降压器。**但电池满电 12.6 V 比电机 12 V 额定值高 5%**：须向厂家确认容许范围并限制运行工况；PWM 限占空比只限制等效平均施加，不等于把瞬时电压钳在 12 V。若必须严格保证电机端不超过 12 V，应为相应支路增加真正的稳压/限压方案并重新核算功率和散热。ACG720 已有项目资料记载原电源口上限 12 V，因此不直接接电池；拟使用 Type-C 时也只拟供**受控 5 V**，不得将电池或 9/12 V PD 输出直接送入 VBUS。

### 两个 USB-C 供电口的实现边界（定板前核实）

- **两个独立 5 V 支路**：BUCK_A、BUCK_B 各自具备输入滤波、输出限流/短路保护、过压防护及足够的负载瞬态余量；两板共地但不把两路 5 V 输出或两个 Type-C VBUS 硬并联。电机堵转、换向及电池临近欠压时，验证两路 5 V 仍满足板端电压要求。
- **USB-C 源端不是简单把 5 V 接到插座**：每口采用适合固定 5 V 输出的源端控制/CC 宣告与受控 VBUS；线缆、插座、开关、保险/限流器件均按宣告电流和热条件选型。5 V / 4 A 是各降压级能力预留，不是 USB-C 单口 4 A 宣告；普通 USB-C 电流宣告最高按规范的 3 A 设计，超过时需完整核实高功率协议及接收端支持情况，本方案不采用。**两块板合计最多 6 A 的对外 5 V / 3 A 预算不是同一根线或同一接口承担**。
- **ACG720 口位与负载待证实**：仓库现无本地索引引用的 ACG720 原厂 PDF，不能凭 Type-C 外形或同系列板卡推断 USB-UART/JTAG/USB2.0 口能给整板供电，也不能把原电源口 6–12 V 规格套在 VBUS。取得对应硬件版本原理图/手册后，核查连接器名称、VBUS 供电路径、开关档位、与 DC 口之间的反灌隔离及摄像头等外设负载；若输入能力达不到测得峰值电流，则不得按本 Type-C 方案定板，应重新评估接口与供电架构。
- **防反灌与调试**：测试时不要在未确认板载电源选择/隔离方式前同时接 DC 电源和供电 Type-C；调试 USB 线可能通过 VBUS 给板子意外上电，分别检查两块板在外部电脑/适配器连接下的电流倒灌、地参考和断电行为。USB-C 接线不改变 FPGA 与 Lichee Pi 的 IO 电平约束。

在所选驱动器、绕组参数和板卡功耗未确定前，可将电池总分配通路按约 **20 A 短时负载目标**布局并保留余量；这不是已测工作电流，也不是最终保险丝额定值。保险丝应保护实际线材、连接器和 PCB 铜箔。高电流动力回流与敏感传感器回流分开布线，在明确的公共地处汇合；驱动器附近按其数据手册布置本地旁路与大容量输入电容。急停至少要可靠禁止两类电机驱动，同时尽量保留控制板供电用于记录故障与受控关机。

## 4. 续航示意

电池标称约 40 Wh。若仅作示例，以 80% 可用能量约 32 Wh、整车**电池侧平均功率** 40–60 W 计算，运行时间约 `32 / 60 ~ 32 / 40 h`，即 **约 32–48 分钟**。这不是续航保证：电池老化、长时间步进保持、坡道负载、相机/显示及 Linux 负载均会改变结果。应在实际运行工况下记录电池电压、电流、各支路电流和驱动温度后重算。

## 5. 定板前必须补齐的测量与确认

1. 用平衡充电器或单体检测仪检查旧电池三节电芯；测静置电压、内阻/负载压降和温度，异常电池停用。
2. 断电测两只步进电机的 A、B 相电阻；选定具体驱动模块后确认限流设置、散热、母线输入电流及保持功耗。
3. **先取得 ACG720 对应版本原理图并确认可供整板电源的 Type-C 口、5 V 输入允许电流/切换方式**；再用限流台式电源配合合规 USB-C 源端，分别测 ACG720＋OV5640 在 Type-C 供电下的启动/稳定/峰值电流、端口电压及供电路径发热，并测 Lichee Pi 4A 在目标计算负载和 USB 外设下的同类参数。确认两板均能在各自 USB-C 口稳定启动与工作，且每口需求不超过其输入及源端宣告能力。
4. 核对 MG513 实物是霍尔还是 GMR 编码器，按对应六针线序检查电源极性；确认驱动模块的持续散热和启动/堵转限流。
5. 核对 IMU、VL53L1X **成品模块**的电源与 I/O 电平。Lichee Pi 4A 的普通 GPIO 不可未经电平核对就直接与 FPGA IO 对接。
6. 改版前先把 `pcb/power/power.kicad_sch` 中 ACG720 的旧 9 V / 3 A 原电源口支路改为独立的 5 V、受控 USB-C 源端（前提是第 3 项验证通过），并检查降压器、源端开关、插座、走线、铜厚和输入总功率的实际承载能力；旧原理图的单路 Lichee Pi 4A USB-C 输出**不可直接复制为“已验证可供 ACG720”**。完成新原理图 ERC/PCB DRC 后，用电子负载和实机分别验证欠压、过流、急停、热稳定性、电机换向时的逻辑支路跌落与噪声，以及两口插拔、短路、断电反灌与线缆压降。

## 6. 资料来源

- WHEELTEC 本地附送资料：`doc/电机/WHEELTEC 直流电机附送资料/.../轮趣直流有刷电机产品说明手册（尺寸、参数、线序）_2026.07.28.pdf`，第 7–9 页（MG513X 参数、编码器与六针线序）。原资料包含限制传播的版权声明，因此原始 PDF 不随公开 GitHub 项目上传。
- ACG720 原厂原理图索引与项目笔记：`doc/fpga/00_资料索引/硬件与引脚核对.md`、`doc/文档.md`。索引指向的 `doc/fpga/01_板卡硬件/ACG720_138K-60K通用原理图.pdf` 当前不在本仓库；**本次未核实 ACG720 Type-C 的整板供电连接，不能将本预算当成已确认的原厂接口规格**。
- 芯路恒本地摄像头指南：`doc/fpga/05_OV5640摄像头/ACM5640-V5摄像头模块用户指南.pdf`，第 1–4 页（模块输入与 V3.3 接口）；摄像头实物版本仍需确认。
- [Sipeed Lichee Pi 4A 供电 FAQ](https://en.wiki.sipeed.com/hardware/en/lichee/th1520/lpi4a/12_faq.html)、[Sipeed 功耗测试](https://wiki.sipeed.com/hardware/en/lichee/th1520/lpi4a/10_test_report.html)。
- [TI DRV8874 产品页](https://www.ti.com/product/DRV8874)、[TI DRV8825 产品页](https://www.ti.com/product/DRV8825)。
- [TDK ICM-42688-P 数据手册](https://product.tdk.com/system/files/dam/doc/product/sensor/mortion-inertial/imu/data_sheet/ds-000347-icm-42688-p-v1.6.pdf)、[ST VL53L1X 数据手册](https://www.st.com/resource/en/datasheet/vl53l1x.pdf)。
- 电池铭牌来自用户照片；3S 电池的满电和充电安全边界可参阅[航模电池安全说明](https://traxxas.com/media/productattach/2970-3S/10/GKC20006-R00-LiPo-battery-fold-out-large%20-%20EN.pdf)，但该说明并不是这块 Yuan H 电池的专用规格书。

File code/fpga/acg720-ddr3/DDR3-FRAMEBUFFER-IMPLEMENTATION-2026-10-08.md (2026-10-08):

# ACG720 与 TY-OV5640 的 DDR3 帧缓存排查及实现

日期为 2026-10-08。开发板是小梅哥 ACG720，工程实际器件为 GW5AT-60B、GW5AT-LV60PG484AC1/I0，摄像头是用户提供的 TY-OV5640。

本次已经在实板打通 **OV5640 → 写 FIFO → DDR3 → 读 FIFO**。静态测试、摄像头内部彩条、摄像头实景三种输入均完成 800×480 整帧验证，用户分别确认 D0～D5 亮、D6 灭、D7 闪。

当前板上运行实景单帧自检版 `0xAF89`。它把一帧存入 DDR 后读回计算 CRC，完成后冻结，不是连续 HDMI 显示程序。仅写 FPGA SRAM，**断电不会保留这次下载的程序**。外部配置 Flash 未改写，HDMI 图像、持续视频、双缓冲及完整时序签核仍未完成。

## 1. 原问题如何判断

此前独立固定模式 BIST 通过了 256 字节读写，原主工程也曾通过 PLL、DDR 校准和摄像头初始化，但新增摄像头 DDR 诊断在 F15、B21 两个复位约束下都仅亮 D0。

旧诊断 D0 表示 DDR PLL 锁定，D1 表示 DDR 校准完成。只有 D0 亮意味着流程还停在校准阶段，并没有完成一次摄像头像素的有效写入和读回比较。因此，当时不能从“诊断没通过”推导出“DDR 芯片损坏”或“读回像素已经发生错误”。

用户随后要求按官方帧缓存向上接摄像头。本次采用第 38 章“串口传图 DDR3 缓存 TFT 屏和 HDMI 显示”的 800×480 帧缓存与时钟为基线，先用其确定数据源证明缓存路径，再逐步接入第 47 章的 OV5640 采集模块。

## 2. 旧诊断中确认了哪些问题

### 2.1 DDR PLL 的 mDRP 控制连接有缺陷

旧顶层把 DDR PLL 的 `pll_init_bypass` 固定为 0。这样外部 `pll_mDRP_intf` 无法接管 PLL 的 mDRP 控制，综合网表中相应逻辑被优化删除。原厂后续 [25K/60K DDR 更新说明](https://fpga.cn/forum.php?mod=viewthread&tid=29815) 要求在锁定延迟后交出控制权。

新基线使用 16 拍锁定延迟，在原始 50 MHz 域控制交接。

```verilog
reg [15:0] pll_lock_reg = 0;
wire pll_mdrp_ready = pll_lock_reg[15];

always @(posedge clk50m or negedge reset_n)
    if (!reset_n) pll_lock_reg <= 0;
    else pll_lock_reg <= {pll_lock_reg[14:0], pll_lock};

// DDR PLL
.pll_init_bypass(pll_mdrp_ready)

// pll_mDRP_intf
.pll_lock(pll_mdrp_ready)
```

`pll_stop` 的变化在原始 50 MHz 域登记，锁定交接完成后才允许触发 mDRP 请求。新静态及摄像头版的综合网表均确认适配器保留。

这是一处确定的源码连接缺陷，但本次没有只修改这一处的旧诊断实板 A/B 对照。新基线同时改变了时钟拓扑与测试流程，不能宣称旧版校准失败的唯一触发原因已经证实。

### 2.2 旧 FIFO 诊断的写入量达不到启动门槛

旧诊断只采集并回放 16 个 RGB565 像素，共 32 字节。写 FIFO 的读侧宽度是 128 bit，这些输入仅形成 2 个读侧数据块。

但它设置 `wr_bust_len=8`，官方适配器只有在 `wfifo_rcount >= wr_bust_len_a` 时才进入 WRITE。也就是需要至少 8 个块、64 个像素；旧诊断送完 16 个像素后，数据仍不足以启动这批 DDR 写入。

这里的 `wr_bust_len` 是适配器一次调度多少个 128-bit 用户块，不能混同为输入像素个数。DDR 的物理 BL8 与这个批次数也不是同一参数。

### 2.3 旧诊断没有等待实际写完成，且比较错位

旧状态机在固定延时后进入读阶段，没有以实际 DDR 写命令完成作为依据；官方适配器又允许独立读取，因此可能拿到本次测试尚未写入的内容。

读 FIFO 的配置是 `FWFT=true`、`OUTPUT_REG=false`。非空时，Q 已经是队首像素，pop 当拍应比较该值。旧代码使用延迟一拍的 `rd_fire_d`，却没有同步锁存 pop 当拍 Q；连续读取时，下一拍 Q 已变为后一个像素，比较会错位。

旧捕获事件还是一次性的 toggle，如果在等待校准时到达，后续等待捕获状态可能错过该事件。代码存在此失败路径，但没有证据表明当时事件确实提前发生。

上述数据量、读写顺序、比较与捕获问题发生在校准之后，不能用来解释旧版 D1 灭。详细证据见 [旧诊断缺陷记录](LEGACY-DDR-DIAGNOSIS-2026-10-08.md)。旧源文件保留，没有覆盖改写。

## 3. 第 38 章本轮综合失败如何解决

原第 38 章生成的 `rd_data_fifo.v`、`wr_data_fifo.v` 在本机 Gowin 1.9.12 / GW5AT-60B 下分别独立综合，都报 `RP0007`，提示当前器件没有 SSRAM 资源。DDR IP 和 PLL 独立综合通过，排查由此收敛到两个生成的 FIFO 实现。

本次采用资料包第 47 章中可以综合的官方 FIFO 实现。替换前逐字节核对两套 `.ipc`、`fifo_parameter.v`、`fifo_define.v`，确认配置完全相同。

| 配置 | 写 FIFO | 读 FIFO |
| --- | --- | --- |
| 输入宽度 | 16 bit | 128 bit |
| 输出宽度 | 128 bit | 16 bit |
| 深度 | 4096 个 16-bit / 512 个 128-bit | 512 个 128-bit / 4096 个 16-bit |
| 容量 | 8 KiB | 8 KiB |
| 实现 | EBR | EBR |
| FWFT / OUTPUT_REG | true / false | true / false |

替换后，独立综合和整工程综合、布局布线均通过。配置与哈希保存在静态工作副本的 `fifo-compatibility.json`，独立综合结果保存在 `.local/framebuffer-first/ip-audit/`。

这一问题解释的是本轮第 38 章的编译失败，不能作为旧已下载诊断校准失败的证据。原厂参考副本 `official-ch38` 的 278 个非 impl 文件保持逐字节一致。

## 4. 新链路具体怎样实现

### 4.1 时钟分别承担什么工作

| 时钟 | 来源 | 负责的逻辑 |
| --- | --- | --- |
| 原始 50 MHz | 开发板晶振，Y18 | SCCB、摄像头复位时序、DDR PLL 参考与 mDRP、心跳 |
| 系统 PLL 50 MHz | 第 38 章 Gowin_PLL | DDR IP 的参考 clk |
| 400 MHz | 独立 DDR PLL | DDR memory clock |
| 100 MHz | DDR IP 的 clk_out | DDR 用户接口、官方适配器、命令计数与地址检查 |
| 摄像头 PCLK | TY-OV5640，B18 | 官方 DVP 采集、完整帧检查、写 FIFO 输入、采集 CRC |
| 33 MHz | 系统 PLL 165 MHz 经 CLKDIV /5 | 读 FIFO 消费、读回 CRC |

DDR PLL 的 clkin/mdclk 来自原始板载 50 MHz，摄像头 PCLK 不参与 DDR 参考时钟。相对旧 camera_pll 拓扑，这使摄像头像素采集的变化与 DDR 参考分开。没有改变摄像头的实物接线。

```mermaid
flowchart LR
    CAM[OV5640 的 8-bit DVP] --> CAP[官方 DVP_Capture<br/>两字节拼接 RGB565]
    CAP --> GATE[选取完整 800×480 帧<br/>检查每行及总像素]
    GATE --> WF[写 FIFO<br/>16 bit → 128 bit]
    WF --> DDR[官方适配器和 DDR3 IP<br/>100 MHz UI / 400 MHz memory]
    DDR --> RF[读 FIFO<br/>128 bit → 16 bit]
    RF --> CHECK[33 MHz 读回<br/>CRC32 比较]
    GATE --> CRC[采集端 CRC32<br/>PCLK 域]
    CRC --> CHECK
```

DDR 型号按资料与 IP 配置为 MT41K128M16JT-125:K，x16、256 MiB，1:4 用户时钟比、128-bit 用户接口、物理 BL8。当前仅验证一帧窗口，没有测试整片容量。

### 4.2 摄像头怎样配置

DDR 校准完成后，摄像头 RST 保持低约 1 ms，释放后等约 20 ms，再用 100 kHz 开漏 SCCB 配置。沿用此前读取 ID 成功的 253 项官方 RGB 表，保留原 PLL、裁剪、HTS/VTS、缩放和 DVP 参数。

| 寄存器 | 配置及读回期望 |
| --- | --- |
| 0x300A / 0x300B | 芯片 ID 0x56 / 0x40 |
| 0x3808 / 0x3809 | 输出宽度 0x03 / 0x20，即 800 |
| 0x380A / 0x380B | 输出高度 0x01 / 0xE0，即 480 |
| 0x4300 | 0x61，沿用官方 RGB565 顺序 |
| 0x501F | 0x01，RGB 输出 |
| 0x503D | 彩条版 0x80；实景版 0x00 |

所有 ID 和 7 个配置寄存器读回一致才置 init_done、点亮 D3。不能仅凭发送了寄存器写事务就判定配置正确。

模块振荡器频率尚未测得，不沿用旧注释“25 MHz”作为事实，也不根据表中注释承诺帧率。用户确认模块排针支持 3.3 V；本次未改变银行供电。PWDN 未引出到 FPGA，沿用现有模块接法，不新增 FPGA XCLK。

RGB 表原来的常量-only `always @*` 在 Icarus 中产生空敏感项、不执行赋值。本地摄像头副本改为显式 addr 敏感项，使仿真初始化同一份常量表，避免未知值被条件判断误当作通过；原参考表未改。

### 4.3 如何保证捕获的是一帧

官方 DVP_Capture 在配置完成后释放复位，舍弃前 10 帧，并按 HREF 把高、低两个字节拼成 16-bit 像素。

新增 `camera_frame_gate.v` 等待帧间空白及下一次完整帧开始。它逐行要求恰好 800 个有效像素，帧结束时要求恰好 480 行、384000 个像素，并检查最后一行已结束。短行、长行、额外像素或异常边界置错误，不能启动成功读回比较。

只向写 FIFO 送这一帧。FIFO 满时记录溢出，不用丢失后的像素填补位置并假装整帧成功。所有完成/错误标志持续保持到复位，避免只发一个异步脉冲而被其他时钟域错过。

### 4.4 如何等待 DDR 写完再读

一帧的数据量和命令数量为

```text
800 × 480 = 384000 个 RGB565 像素
384000 × 2 = 768000 字节
768000 / 16 = 48000 个 128-bit 用户数据块
```

官方适配器使用地址单位为 16-bit 字，单个 BL8 用户块地址递增 8。监视器要求读、写接受的地址分别为 0、8、16……383992，各恰好 48000 个命令。这里的地址上限 384000 不能当作字节数。

800×480 基线沿用第 38 章的 200-block 调度批次，完整帧恰好是 240 批。读调度只有在实际接受全部写命令，且采集完整帧检查通过后才打开；读完规定的命令数后关闭，避免自动循环读混入其他内容。

监视器同时检查无请求响应、响应超量和超时。静态测试在 pop 当拍逐像素比较；摄像头测试在同一采样时刻更新 CRC。

### 4.5 CRC 和跨时钟数据怎样处理

采集 CRC 只对实际接受进入写 FIFO 的像素计算。读回 CRC 只对读 FIFO 非空且实际 pop 的像素计算。两端均按高字节、低字节次序使用 CRC32，反射多项式为 0xEDB88320，初值与最终异或均为 0xFFFFFFFF。

最后一个输入像素处理后，采集 CRC 冻结。帧结束后才置完整帧通过标志，再经两级同步进入 UI 和读时钟域，建立稳定多位数据的完成握手。读回恰好 384000 个像素后，将两端 CRC 比较；还必须没有帧尺寸、FIFO、命令、响应或超时错误，D5 才亮。

CRC 一致证明本次采集数据经过缓存后得到一致的校验值，并非逐像素独立比对；CRC 存在碰撞可能，也不能证明画面颜色和 HDMI 显示正确。静态版另有实际逐像素比较通过的证据。

## 5. 仿真与实板证据

### 仿真覆盖

- 静态控制器覆盖空读暂停、字节/行回绕、末像素损坏、输入溢出、错误写地址、提前读、无请求响应、超时及复位，并单独跑完 384000 像素。
- 使用实际官方数据源及 8→16 拼接模块，确认静态图案期望序列，避免只测自造数据源。
- 摄像头测试使用实际官方 DVP_Capture，覆盖异步 PCLK/UI/读时钟、FWFT 暂停、完整帧、短行、溢出和末像素损坏。
- 摄像头完整帧仿真 CRC 与独立 Python zlib 金值一致，测试序列的 CRC 为 0xCC8B28AB。这是仿真图案值，不是实景帧 CRC 的实际数值。
- 配置控制器使用实际 ROM 和事务级 SCCB 模型，确认 253 次写、2 次 ID 读、7 次配置读；错彩条或尺寸读回均拒绝 init_done。该模型不替代 SCCB 电气时序验证。

### 实板结果

| 阶段 | User Code | 比较方式 | 用户实际反馈 |
| --- | --- | --- | --- |
| 第 38 章静态图案 | 0x41A4 | 完整帧逐像素一致 | D0～D5 亮、D6 灭、D7 闪 |
| OV5640 内部彩条 | 0x4FCF | 帧尺寸正确，完整帧 CRC 一致 | D0～D5 亮、D6 灭、D7 闪 |
| OV5640 实景 | 0xAF89 | 彩条关闭读回确认，完整帧 CRC 一致 | D0～D5 亮、D6 灭、D7 闪 |

实景版相对彩条版只有两项源码变化，即表中 0x503D 改为 0x00、该寄存器读回期望改为 0x00，其余 src 文件逐字节一致。通过结果来自用户观察对应位流的 LED；下载工具没有自动测得 LED、实景 CRC 数值或 HDMI 图像。

三次 SRAM 下载均完成 100%，Status 为 0x70026020。下载身份与成功状态证明程序写入完成；DDR 和摄像头运行结果仍以对应 LED 测试判据为证据。无需外接逻辑分析仪，也没有进行外部探头接线。

## 6. 当前位流、文件和复现步骤

| 文件 | 用途 |
| --- | --- |
| `rtl/framebuffer_frame_test.v` | 静态完整帧逐像素测试 |
| `rtl/camera_frame_gate.v` | 摄像头完整帧选择和尺寸检查 |
| `rtl/framebuffer_camera_test.v` | 摄像头输入 CRC、DDR 命令计数、读 FIFO CRC |
| `tests/framebuffer_camera_test_tb.v` | 实际 DVP 模块、完整帧及故障注入仿真 |
| `tests/ov5640_readback_ctrl_tb.v` | 配置表和关键寄存器读回仿真 |
| `.local/framebuffer-first/ch38-camera-live/` | 当前实景工程、修改后的本地摄像头控制器和官方 IP |
| `.local/framebuffer-first/ch38-camera-live/build-audit-20261008.json` | 实景源码差异、位流哈希、时序端点记录 |
| `.local/logs/ch38-camera-live-*.log` | 实景编译、下载、配置控制器仿真日志 |

原厂工程、加密 IP 和位流保留在本机忽略目录 `.local`；纳入版本管理的是新增 RTL、测试、构建入口和说明，单独取出这些文件不能代替本地依赖。

工程准备脚本已纳入 `scripts/`，新增 SCCB 控制源码在 `rtl/camera_init/`，历史实板记录在 `verification/2026-10-08/`。按 [重建说明](scripts/README.md) 放置官方参考与 IP 后，依次准备静态、彩条和实景工程。已在独立临时目录确认生成的 src 文件与本次通过版本逐字节一致；脚本不生成新的硬件通过记录，也不会编译或下载。

在项目的 `code/fpga/acg720-ddr3` 目录运行官方工具编译

```powershell
& 'C:/Gowin/Gowin_V1.9.12_x64/IDE/bin/gw_sh.exe' 'build_ch38_camera_live.tcl'
```

恢复当前通过的实景自检位流前，先重新扫描下载器。location 8740 是本次记录，换 USB 端口后须使用扫描结果，不照搬旧值。

```powershell
$programmer = 'C:/Gowin/Gowin_V1.9.12_x64/Programmer/bin/programmer_cli.exe'
& $programmer --scan-cables F
# 确认当前 cable-index 和 location，再执行 SRAM 下载。
$frameFs = (Resolve-Path '.local/framebuffer-first/ch38-camera-live/impl/pnr/ch38_camera_live.fs').Path
& $programmer --device GW5AT-60B --operation_index 2 --fsFile $frameFs --cable-index 1 --location 8740 --frequency 15MHz
```

复现本次仿真依赖本机已安装的 `.local/tools/iverilog/bin/iverilog.exe` 与 `vvp.exe`，例如完整摄像头帧测试

```powershell
& '.local/tools/iverilog/bin/iverilog.exe' -g2012 -s framebuffer_camera_test_tb `
  '-Pframebuffer_camera_test_tb.FRAME_HEIGHT=480' `
  '-Pframebuffer_camera_test_tb.FULL_PASS_ONLY=1' `
  -o '.local/framebuffer-first/camera-full-test.vvp' `
  'rtl/framebuffer_camera_test.v' 'rtl/camera_frame_gate.v' `
  '.local/framebuffer-first/ch38-camera-bars/src/DVP_Capture.v' `
  'tests/framebuffer_camera_test_tb.v'
if ($LASTEXITCODE -eq 0) {
  & '.local/tools/iverilog/bin/vvp.exe' '.local/framebuffer-first/camera-full-test.vvp'
}
```

当前实景位流的 SHA256 为

```text
A718EFC364FEB9A6B47AD333686F0518D76A56DAD1955ABBA607262CAE790553
```

静态通过位流 SHA256 为 `DD7959D0C266BD507D50DE8FBCF6DE9F9487E5F3B2076F643A168929D81A6222`，彩条通过位流为 `5C13FEA6833E57650914D20B5983ED79A3BC3F629AAC3DCAD06833C74970BD92`。分别位于对应工作副本的 `impl/pnr/`，没有互相覆盖。

实景和彩条版的灯态定义相同

| 灯 | 含义 |
| --- | --- |
| D0 | 系统 PLL 锁定 |
| D1 | DDR PLL 锁定 |
| D2 | DDR 校准完成 |
| D3 | 摄像头 ID、尺寸、RGB565、彩条开关读回通过 |
| D4 | 整帧 DDR 写命令完成 |
| D5 | 整帧尺寸正确、读回 CRC 一致，且无其他错误 |
| D6 | 任一测试错误 |
| D7 | 心跳 |

S0 / F15 低有效复位，重新启动一次完整自检；旧主工程 B21 / S4 的按键定义不要套用到本版。

## 7. 断电保存、HDMI 与后续工作的边界

目前通过 `operation_index 2` 下载到 FPGA SRAM，配置在断电后丢失。重新上电会依开发板启动设置从配置 Flash 原有内容启动，本次没有核实该旧内容的图像表现，也没有将当前程序写入 Flash。

当前读 FIFO 消费者是 CRC 检验逻辑，检验完成后停止，摄像头输入也只保留一帧。虽然保留了官方 HDMI 输出相关模块，但这不等于视频数据已经按显示时序连续供给 HDMI。没有接显示器验证，不能承诺当前或断电后看到图像。

若后续要求连续显示并断电恢复，应先把读 FIFO 消费接回显示请求，建立帧边界与读写缓冲管理，再在显示器上检查图像、颜色、重复帧和撕裂。确认最终显示位流后，再将它写入配置 Flash并冷启动复测。不要把本次单帧 CRC 自检直接当作最终视频固件固化。

时序方面，当前实景版报告仍有 206 个 setup、56 个 hold 违反端点，涉及跨时钟、私有 PHY 和 HDMI 路径。已定义 50 MHz、33 MHz、100 MHz UI 及保守 100 MHz PCLK 约束，没有使用全局 false path 隐藏报告。PCLK 在 PNR 中使用 PRIMARY 时钟网络，BSRAM 35/118、SSRAM 0。实板单帧通过不能替代 CDC、复位和完整时序审核。

尚未验证 256 MiB 全容量、唯一地址覆盖、长时间稳定性及乒乓帧缓存。当前可以确认的工程成果是静态和彩条、实景的完整帧缓存链路均通过；旧校准失败的唯一触发原因仍缺单变量实板对照。

## 8. 资料与关联记录

原厂资料根目录为 `C:/Users/sc/Documents/Dev/Hardware/fpga/小梅哥ACG720国产高云FPGA教学开发板资料/`，主要参考 60K 第 37、38、47 章、ACG720 硬件原理图和引脚分配表。模块针脚依据用户提供的 TY-OV5640 照片和 `T-OV5640-PCB-V1.0-模型.pdf`，没有把 ACM5640 模块原理图当成 TY 模块的电路证明。

- [静态整帧验证与 FIFO 兼容性证据](FRAMEBUFFER-TEST-RESULT-2026-10-08.md)
- [摄像头彩条与实景下载、配置和灯态](CAMERA-FRAME-TEST-2026-10-08.md)
- [旧诊断缺陷及未确认根因](LEGACY-DDR-DIAGNOSIS-2026-10-08.md)
- [官方帧缓冲优先方案与硬件核对](FRAMEBUFFER-FIRST-PLAN-2026-10-08.md)
- [历史交接](DEBUG-HANDOFF-2026-10-06.md)

原始资料包、配置 Flash、已通过位流和无关 PCB 文件均未改写。许可证已解决，复现无需更改网卡地址或重新处理许可证绑定。

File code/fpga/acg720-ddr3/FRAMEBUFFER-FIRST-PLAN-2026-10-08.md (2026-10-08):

# 从官方帧缓冲向上接入 TY-OV5640

2026-10-08。用户本轮要求先研究官方帧缓冲和开发板硬件，改变此前从摄像头向 DDR 逐级诊断的方向。本轮完成资料和源码核对、参考副本整理；没有编译、下载或改变板上配置。

## 结论与实施顺序

以 GW5AT60K 目录下第 38 章 `ch38_uart_ddr3_tft_hdmi.zip` 为新基线，先验证它的写 FIFO → DDR3 → 读 FIFO，再把输入替换为第 47 章的 OV5640 配置与 DVP 捕获。摄像头先输出内部彩条，最后输出实景。

1. 审核第 38 章的时钟、复位、PLL mDRP 控制权及 FIFO 容量边界；在独立工作副本处理已证实的问题，保留未改动的参考副本。
2. 使用官方已有 `USE_TEST_DATA="TRUE"` 模式，检查校准、确定数据写入、地址对应的读回与整帧统计。先保持 800×480。
3. 使用配套串口传图工具传入一张完整静态图，验证真实输入到帧缓存的路径。没有 HDMI 显示器时先取得内存读回证据；HDMI 图像仍单独标为未验证。
4. 在已验收的帧缓冲工作副本中接入 OV5640，仍输出 800×480 RGB565，开启芯片内部彩条。只改输入、摄像头配置和相关接口约束。
5. 核对每行 1600 字节、每帧 480 行和 384000 个有效像素，确认无 FIFO 溢出、读回一致；再关闭彩条输出实景。
6. 最后一起调整摄像头尺寸、帧地址范围、FIFO 调度和显示时序到 1280×720；随后考虑完整帧的双缓冲。

这些是后续验收项，尚未执行。历史 256 字节 BIST 通过不能替代整帧验证。10 月 7 日 0x2D41 修正版下载成功，但尚未取得对应 LED 反馈；本轮不推断它已解决校准。

## 官方源码已核实的参数

参考副本位于 `.local/framebuffer-first/official-ch38/`，从原 ZIP 提取非 `impl/` 文件，未修改内容；包含工程、源码、IP 配置及官方 `.rao`。这不是本轮编译产生的工程或位流。

原 ZIP SHA256：`7539193CF056A9FDD0600BDFAB897DB64ED1ADACB2DCA1F9D8F8EF8D93CD2836`。

| 项目 | 第 38 章实际源码 |
| --- | --- |
| 器件 | GW5AT-60B，GW5AT-LV60PG484AC1/I0 |
| 默认尺寸 | 800×480 |
| 用户像素 | 16 位，每个像素由先到的高字节和后到的低字节组成 |
| 帧大小 | 384000 个 16-bit 像素，768000 字节 |
| 地址范围 | min=0，max=800×480；一次 BL8 的命令地址递增 8，不能把 max 当字节数 |
| DDR | 400 MHz memory_clk，1:4，128-bit 用户数据接口 |
| 输入逻辑时钟 | 50 MHz |
| 显示时钟 | 33 MHz pixelclk，165 MHz pixelclk5x，800×480 TFT 时序同步输出 HDMI |
| 串口 | `Baud_Set=5`，实际 1562500 baud；教材另一处 2000000 的文字不适用于这份源码 |
| 输入格式 | 连续像素字节；源码没有图像包头解析。复位后字节和像素计数重新开始，必须传满一帧 |
| 测试输入 | `USE_TEST_DATA="TRUE"`，默认 `DISP_MODE=0`，输出列号字节模式；不是默认输出标准彩条 |
| 复位、系统时钟 | S0/F15 低有效；Y18/50 MHz |
| 串口输入 | J21，板载 CH340E 的 FPGA_UART_RX |
| LED | D0=显示/系统 PLL 锁定，D1=DDR 校准完成，D2=收到完整帧后翻转；D3 输出 UART RX 电平，不是第 47 章的 PLL 灯 |

第 38 章默认测试源每行输出 1600 个字节，按列号低 8 位递增，经 8→16 转换得到 `0x0102, 0x0304, ...`。验证时按实际地址、行长与字节顺序计算期望值；短重复模式的某个采样窗口一致不能证明整帧地址正确。

800×480/33 MHz 是例程的 TFT 时序，普通 HDMI 显示器未必接受。先用它核验缓存；需要普通 HDMI 显示器验收时，应配套切换到完整的标准显示时序，不能只修改宽高参数。

第 38、47 章的以下文件逐字节相同：

- `src/ddr3_ctrl_2port/fifo_ddr3_adapter.v`
- `src/ddr3_memory_interface/ddr3_memory_interface.ipc`
- `src/ddr_pll/ddr_pll.v`

`ddr3_ctrl_2port.v` 文件不同，不能不检查接口就整文件替换。DDR IP 的 `.ipc` 相同也不代表本轮已经比较全部加密实现。

## 基线本身必须审核的问题

- 第 38 章顶层仍将 `pll_init_bypass` 接常数 0，与之前发现的外部 mDRP 控制权问题相同。可以沿用已查证的原厂更新方法，但 10 月 7 日修正版尚无实板校准确认，不能称为已经验证成功的解决方案。
- 第 38 章将 `wr_load`、`rd_load` 留空；正式工作副本应给出明确连接。静态连续输入基线可明确置 0并依靠地址回绕；接摄像头后按帧起点重置写地址，按显示帧起点重置读地址，同时检查 FIFO 复位和在途返回数据。
- 第 38 章 `burst_len=DISP_WIDTH[10:2]`，800 宽时为 200 个 128-bit 传输；第 47 章使用 `[10:3]`，1280 宽时为 160。这里是适配器一次调度的传输数量，不能与 DDR 固定 BL8 混为一谈。
- 若直接将第 38 章的宽度改为 1280，同一切片会得到 320，赋给 8-bit 的 burst_len 后截断成 64。因此升级分辨率时必须同时核对批次长度和 FIFO 容量，不能仅改 IMAGE_WIDTH。
- FIFO 的生成参数文件给出：写 FIFO 为 4096×16-bit → 512×128-bit，读 FIFO 为 512×128-bit → 4096×16-bit，各为 8 KiB。`.ipc` 中的 DEPTH 编码不能直接当作地址位数计算容量。当前读调度在 `rfifo_wcount<=200` 时请求 200 个字，正常批次合计 400 小于 512；源码未显式计入尚未返回的读请求，验收仍需观察占用量、在途请求和返回有效。不能仅凭阈值就宣称已发生溢出，也不能只凭容量估算就宣称实板稳定。
- 写满和读空接口已存在，但顶层未使用。摄像头没有像普通流接口那样的反压能力；写满应产生丢帧/溢出记录，避免把缺像素的一帧当成完整帧。
- 官方源码中的读写地址范围相同，是单帧区域循环读写。双端口不等于双帧缓冲，后续需要完整帧提交和切换机制才能避免读到一半旧帧、一半新帧。
- 先取得基线的校准和读回证据，再添加 GAO；添加观测逻辑后复核校准、布局布线和时序。不得把“加了探针后失败”直接归因于 DDR 硬件。

## 摄像头适配的明确契约

保留基线的 DDR IP、DDR PLL、参考时钟、读写 FIFO 和已验收的显示端。摄像头 PCLK 只驱动 DVP 捕获与写 FIFO 的写端，不给 DDR 提供参考时钟。基线 DDR PLL 输入来自板上 50 MHz。

| 接口/配置 | 800×480 初始方案 |
| --- | --- |
| SCCB 地址 | 7-bit `0x3C`，总线写/读地址字节为 `0x78/0x79` |
| 初始化判据 | 读取 `0x300A=0x56`、`0x300B=0x40`，再读回关键配置；不能只用初始化计数走完表示成功 |
| SCCB 时钟 | 沿用现有已初始化成功的 100 kHz 开漏控制器，确认模块端上拉 |
| RST、PWDN | RST 低有效；PWDN 高有效，正常运行保持低。没有引出 FPGA 控制的 PWDN 仍需有明确电平 |
| 参考时钟 | TY 模块照片有振荡器，但未读清频率；新 PDF 不给出频率，也未引出 XCLK。旧记录“25 MHz”尚未独立证实；不要把 ACM5640 原理图的 24 MHz 自动套到 TY 模块 |
| 输出选择 | 第 47 章 RGB 表作为起点；`0x300E=0x58` 配置 DVP，`0x4300=0x61`、`0x501F=0x01` 对应 RGB565 / RGB ISP |
| 输出尺寸 | `0x3808/09=0x0320`，`0x380A/0B=0x01E0`；裁剪、缩放、HTS/VTS、PLL 和分频应配套核对，不能只改这四个寄存器就宣称帧率正确 |
| 初始彩条 | 初始化完成后 `0x503D=0x80` 开启标准彩条；通过后写回 `0x00` 输出实景 |
| 像素排列 | 首字节 `{R[4:0],G[5:3]}`，次字节 `{G[2:0],B[4:0]}`；拼接后 R=bits15:11、G=10:5、B=4:0 |
| DVP 捕获 | 沿用官方按 PCLK 上升沿取数、HREF 高电平拼字节的实现，实测确认采样边沿与同步极性；每行重新对齐字节相位 |
| 写 FIFO | `wr_clk=PCLK`，`wfifo_din=DataPixel`，`wfifo_wren=DataValid && 允许接收本帧` |
| 帧起点 | 第 47 章 `DataVs` 是反相、延迟后的 VSYNC；适配器检测 load 上升沿，不能直接把原始 VSYNC 替代它而不核对语义 |
| 有效数据 | 丢弃初始化后的不稳定帧，再从完整帧边界开始接收；官方捕获模块丢前 10 帧，因而初始化灯亮后不会立即输出 DataValid |

显示顶层里的 TFT 总线接法看似把红色接低位，但 `disp_driver` 内部按 `{Red,Green,Blue}` 从像素高位拆分，再接至相应 TFT 信号。因此不能只根据 `TFT_rgb` 下标把内存像素误判成 BGR565，也不要随意交换红蓝。

## 模块与开发板的硬件核对

用户确认模块为 TY-OV5640，照片丝印 `T-OV5640-PCB-V1.0`，18 针。新 PDF 给出的编号与照片一致；本轮先前“24 针”提问错误，已更正。

照片方向为镜头在上、排针在下，左到右的两排丝印为：

```text
GND  SCL  SDA  D0   D2  D4  D6  PCLK PWDN
3V3  VS   HS   RST  D1  D3  D5  D7   NC
```

对应图纸编号依次为上排 17/15/13/11/9/7/5/3/1，下排 18/16/14/12/10/8/6/4/2。`HS` 对应捕获端 HREF，`VS` 对应 VSYNC；NC 保持不接。

新 PDF 标注 DOVDD=1.8 V，输入为 3V3，但未给出模块电路或电平转换实现。用户随后明确确认**模块排针支持 3.3 V**。实施按用户确认的排针接口规格，保持已有 3.3 V I/O 方案；资料中的 1.8 V 作为未解释的差异保留，不能把它当成已测得的排针电平，也不据此自动改跳帽。若有后续实测，记录 SCCB 和 DVP 排针实际高电平。

开发板通用原理图已核对第 1、2、3、4、9、10、11、12 页及管脚表。关键硬件事实如下：

- P4 是 20 针摄像头接口，与 TY 的 18 针顺序不同，不能直接对应插接。P4 的 SCL/SDA 各有 4.7 kΩ 上拉到 3.3 V，PWDN 有 4.7 kΩ 下拉。
- 当前工作副本使用 P7 的 GPIO0，并未使用 P4 的摄像头映射；P4 上拉不会自动给 P7 的 SCCB 提供上拉。
- P7 属于 Bank 2，使用可配置的 VCCIO。P6 的 1–2/3–4/5–6 分别选择约 2.5/1.8/1.5 V，7–8 为 3.3 V 连接；当前跳帽位置本轮未实测。CST 的 BANK_VCCIO 不会改变硬件电压。
- 同一 Bank 的 S0～S4 和拨码开关经过 SN74LVC8T245 双电源转换器，3.3 V 的按键侧与可变 VCCIO 侧分开。今后若改变 VCCIO，需要按整个 Bank 核对，不只改摄像头一个引脚。
- 板载 USB-UART 为 CH340E，接口 J2，FPGA_RX=J21、FPGA_TX=M15。FX2 数据 USB、USB-JTAG 和 CH340 UART 是不同通路。本轮枚举到的 COM5 来自 FTDI 下载器，不能拿它代替第 38 章的 CH340 UART。
- DDR3 为 MT41K128M16JT-125:K，x16、1.5 V，256 MiB，DDR3_VTT/VREF 约 0.75 V；24 MS/s 外部分析仪不适合测它的高速信号。

当前源码映射和原理图 P7 引脚的对应关系如下。它是源码/图纸核对结果，本轮没有逐线验证实物接线；接探头时同时核对模块丝印和排针 1 脚方向。

| 摄像头信号 | TY 编号 | FPGA 球号 | P7 针号 |
| --- | --- | --- | --- |
| SCL | 15 | B13 | 14 |
| SDA | 13 | D15 | 16 |
| RST | 12 | C14 | 17 |
| VS / VSYNC | 16 | C13 | 13 |
| HS / HREF | 14 | D14 | 15 |
| PCLK | 3 | B18 | 26 |
| D0 | 11 | C15 | 18 |
| D1 | 10 | B15 | 19 |
| D2 | 9 | B16 | 20 |
| D3 | 8 | D17 | 21 |
| D4 | 7 | C17 | 22 |
| D5 | 6 | E16 | 23 |
| D6 | 5 | D16 | 24 |
| D7 | 4 | B17 | 25 |
| PWDN | 1 | 当前未约束 | 模块侧明确保持低 |
| GND | 17 | 板地 | P7-12 或 P7-30 |
| 3V3 | 18 | 电源 | P7-29 |

**P7-11 是 5 V 电源，P7-29 是 3.3 V 电源；都不是分析仪地线。** 逻辑分析仪是输入探头，不用其电源输出给摄像头供电。

## 24 MHz / 8 CH 逻辑分析仪怎么用

用户使用 Logic，探头未接。本机检测到 Logic 2.4.48 和 USB VID_0925/PID_3881 分析仪；该 USB ID 不足以确定分析仪具体型号、输入阈值或耐压。本轮未发起采集，没有验证实际识别与解码结果。按模块排针 3.3 V 方案，在分析仪规格允许 3.3 V 输入的前提下接以下信号。

| 通道 | 首轮信号 | 建议位置 | 可回答的问题 |
| --- | --- | --- | --- |
| GND | 共地 | P7-12 / P7-30 或模块 GND | 建立共同参考 |
| CH0 | SCL | P7-14 或模块 SCL | 配置时钟、启动停止时序 |
| CH1 | SDA | P7-16 或模块 SDA | SCCB 地址、ACK、寄存器写入/读回 |
| CH2 | RST | P7-17 或模块 RST | 复位低电平和释放到开始配置的延时 |
| CH3 | PWDN | 模块 PWDN | 是否保持正常运行所需低电平 |
| CH4 | VSYNC | P7-13 或模块 VS | 帧周期、是否持续出帧 |
| CH5 | HREF | P7-15 或模块 HS | 有效行数、行周期、行有效时间 |
| CH6 | 预留 | 后续工作副本可导出状态到空闲 GPIO | DDR 校准完成的慢电平 |
| CH7 | 预留 | 后续工作副本可导出状态到空闲 GPIO | 帧接收/溢出的慢标志 |

CH6/7 是未来诊断输出方案，当前工程没有这些新增输出。避免将 PCLK 直接当作 24 MS/s 的可靠采样时钟，也不要把单周期 100 MHz 的 DDR 握手直接导出给它观察；应转成持续电平或展宽事件。

建议 Logic 首轮用 8 MS/s、约 1 秒采集；如设备下拉列表没有该值，选择可用的 4 MS/s 或更高采样率。RST 下降沿触发或开始采集后复位，添加 I2C 解码器：SCL=CH0、SDA=CH1。现有 SCCB 为 100 kHz，8 MS/s 约有 80 个样本/位。确认真实设备处于连接状态，防止误读 Demo 数据。当前摄像头工程复位为 S4/B21，第 38 章原版为 S0/F15，必须按实际下载的工程操作。

Logic 2 默认显示 7-bit 地址，因此看到 `0x3C` 正常，不应期待地址字段一定显示 `0x78`。检查实际芯片 ID、关键寄存器读回、ACK，以及配置完成后 VS/HREF 是否持续活动。100 kHz 下 253 条约 4 字节配置的总线耗时粗估约 0.1 秒，实际还包含等待和读回；采集时间须覆盖完整初始化。

第二轮按 VSYNC 边沿触发，抓取多个完整帧，统计有效行数和帧周期；分辨率和字节数由 FPGA 内部 PCLK 域计数核验。八条数据线加 PCLK/HREF/VSYNC 共 11 条，8 通道也不能同时覆盖完整 DVP。

24 MHz 是采样率，即约 41.7 ns/样本，不能代表可可靠捕获 24 MHz 时钟。按约 4 倍过采样作粗略规划，6 MHz 已接近边界，具体还取决于脉宽、采样相位、阈值和解码要求。摄像头实际 PCLK 需要内部测量确认，正常视频不靠这台分析仪直接复原像素；400 MHz DDR/800 MT/s 和 HDMI 同样不在它的适用范围。

## Gowin GAO 与外部分析仪分工

第 38 章已经带有 `.rao`，采样时钟为 loc_clk50m、深度 16384，触发 UART 字节有效，探针含 UART 字节、16-bit 输入像素、像素有效、读 FIFO 数据与读使能。

它能作为配置起点，但读 FIFO 信号属于 33 MHz 显示域，不能仅靠 50 MHz 异步采样就认定每个读像素都被准确记录。后续分别使用各自时钟域的 GAO 核/采集配置：

- 50 MHz 控制域：PLL 锁定、DDR 校准、SCCB 状态、帧接收总数。
- DDR `ui_clk` 域：cmd/cmd_en/cmd_ready、addr、wr_data/en/rdy、rd_data/valid、FIFO 占用、溢出、在途读请求。
- 摄像头 PCLK 域：D[7:0]、HREF、VSYNC、拼接后的像素与 DataValid、每行字节数和每帧行数。
- 显示域：读 FIFO empty、读使能、像素和显示帧边界。

16384 个采样点不能直接覆盖整帧所有像素。整帧验证需计数、地址对应的比较或 CRC；GAO 用于定位失败窗口。新观测逻辑完成后仍需重做布局和时序检查。

本机现有 `C:/Gowin/Gowin_V1.9.12_x64/IDE/bin/gao_analyzer.exe`、`gao_sh.exe` 可用；无需自写逻辑分析仪工具。资料包已有“小梅哥串口传图V4软件和图片素材.rar”，后续优先用它验证静态图输入。

## 资料位置

资料包根目录：`C:/Users/sc/Documents/Dev/Hardware/fpga/小梅哥ACG720国产高云FPGA教学开发板资料/`。

- 硬件：`06_硬件图纸/ACG720-138&60K通用原理图.pdf`，主要证据页 2/3/4/9/10/11/12；`04_引脚功能信息/高云 ACG720-138&60K通用管脚分配表.xlsx`。
- 例程：`02_例程源码/GW5AT60K/第37章 二端口DDR3控制器/`、第 38 章、第 47 章；第 38 章工程和 IP 配置均明确为 60B。
- 教材：`01_教材文档/小梅哥高云 ACG720-138&60K通用FPGA开发板自学教程/`，第 37/38/47 章。
- TY 模块：用户提供 `C:/Users/sc/Downloads/T-OV5640-PCB-V1.0-模型.pdf`，共 1 页；它是机械/针脚图，不是完整电路原理图。
- OV5640 数据手册：`09_套餐配套模块资料/摄像头/ACM5640-V5/Datasheet/OV5640_CSP3_DS_2.01_Ruisipusheng.pdf`，PDF 页 43/87/93/94/103/104/140/142。
- ACM 模块资料只作比较：18 针旧版 `ACM5640原理图.pdf` 和 20 针 V5 手册不是 TY 模块的电路证明；旧版 ACM 图纸为 24 MHz 晶振、2.8 V DOVDD。
- Saleae 采样率说明：https://www.saleae.com/support/logic-software/capturing-data/what-sample-rate-is-required
- Saleae I2C 解码说明：https://new.saleae.com/support/protocol-analyzers/analyzer-user-guides/using-i2c

PDF 页面文本、渲染和源码审阅摘录保存在 `.local/review/20261008/`。原始资料包、历史位流和无关 PCB 文件保持原状。

参考副本验证：278 个非 impl 文件与原 ZIP 逐字节一致，工程所有启用文件均存在。本轮只完成静态资料/源码核对，没有执行 RTL 仿真、综合、时序验证或实板测试。

## 后续执行进展（2026-10-08）

上述“仅核对资料”指方案整理阶段。随后已建立独立 `ch38-frame-test` 工作副本，完成仿真、综合、布局布线和 SRAM 下载。用户反馈 `0x41A4` D0～D5 亮、D6 灭、D7 闪，静态 800×480 帧经写 FIFO、DDR、读 FIFO 后逐像素比较通过。具体修正、编译兼容性问题、位流哈希、时序限制见 [FRAMEBUFFER-TEST-RESULT-2026-10-08.md](FRAMEBUFFER-TEST-RESULT-2026-10-08.md)。

用户无法接入外部逻辑分析仪，采用板上状态灯和内部计数/CRC。摄像头彩条版 `ch38-camera-bars` 沿用已通过的 DDR 时钟和缓存，保持现有 TY-OV5640 接线，设置 800×480 RGB565，读回确认格式/尺寸/彩条寄存器，捕获一帧后比较采集端和读 FIFO 端的 CRC32。完整帧和配置控制器仿真通过，彩条 `0x4FCF`、实景 `0xAF89` 均由用户确认 D0～D5 亮、D6 灭、D7 闪。当前实景单帧自检仅下载 SRAM，不断电保存，连续 HDMI 未验证；完整过程见 [排查与实现文档](DDR3-FRAMEBUFFER-IMPLEMENTATION-2026-10-08.md)。

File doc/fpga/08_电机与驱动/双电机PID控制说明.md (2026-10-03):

# 双电机 PID 控制

> **2026-10-02 电源板接口更新：**下文实现和测试记录针对 TB6612 的独立 IN1/IN2、PWM、STBY 接口。当前电源板已选用 AT8236 双路模块，每通道只有两个 IN，需要将 PWM、方向及禁止状态适配到这两个输入，核对引脚约束和复位默认状态后才能使用；不能只连接原方向引脚而丢弃 PWM。见 [AT8236 模块资料核对](../../电机/AT8236模块资料核对.md)。本次资料核对未修改 RTL，历史仿真/时序结果不等于已验证 AT8236 接法。

## 当前交付状态（2026-09-13，时序收敛续作）

已核实 RPM 多周期优化此前就已完成。此前 RPM 优化后的真实报告为 Fmax=25.339MHz、setup slack=-19.464ns，瓶颈是 PID IP 输出 → adapter 命令寄存器的组合缩放，并非 RPM 周期相加。此次将 `dual_pid_adapter` 的精确缩放改为流水线，保护的 PID IP、`pid_input_processor`、`tb6612_motor_driver` 和 RPM/遥测 RTL 均未改动。

实际 ModelSim 八项自检全部 PASS；adapter 额外遍历全部65536个 signed16 输入，连续每拍左右交替，覆盖默认及32767全幅参数、流水线各阶段停止撤销、禁用与复位。默认数值与原公式完全一致；延迟增加4拍（80ns），吞吐率仍为每拍一个输入。

Gowin V1.9.12、GW5AT-LV138PG484AC1/I0、50MHz/20ns 当前源码综合及P&R结果：
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

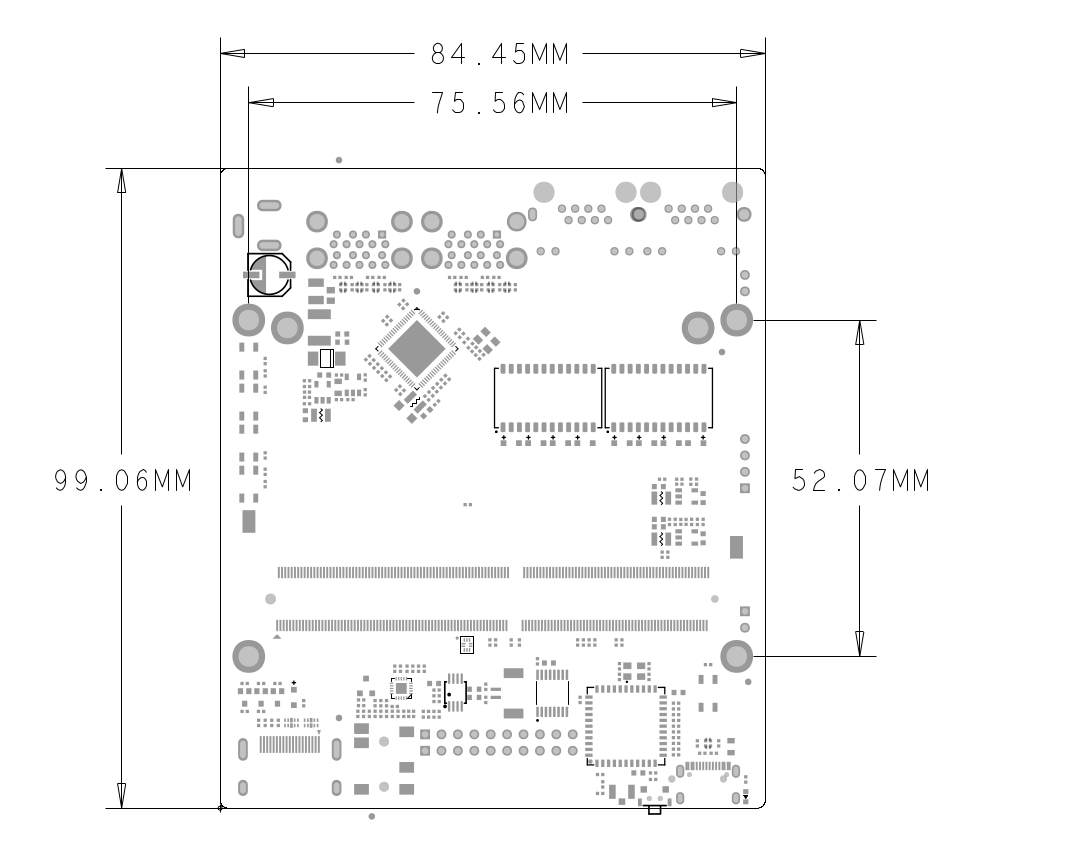
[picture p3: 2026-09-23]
model/BE11300D28AD57C96EC11B6DEDBB3751.bmp

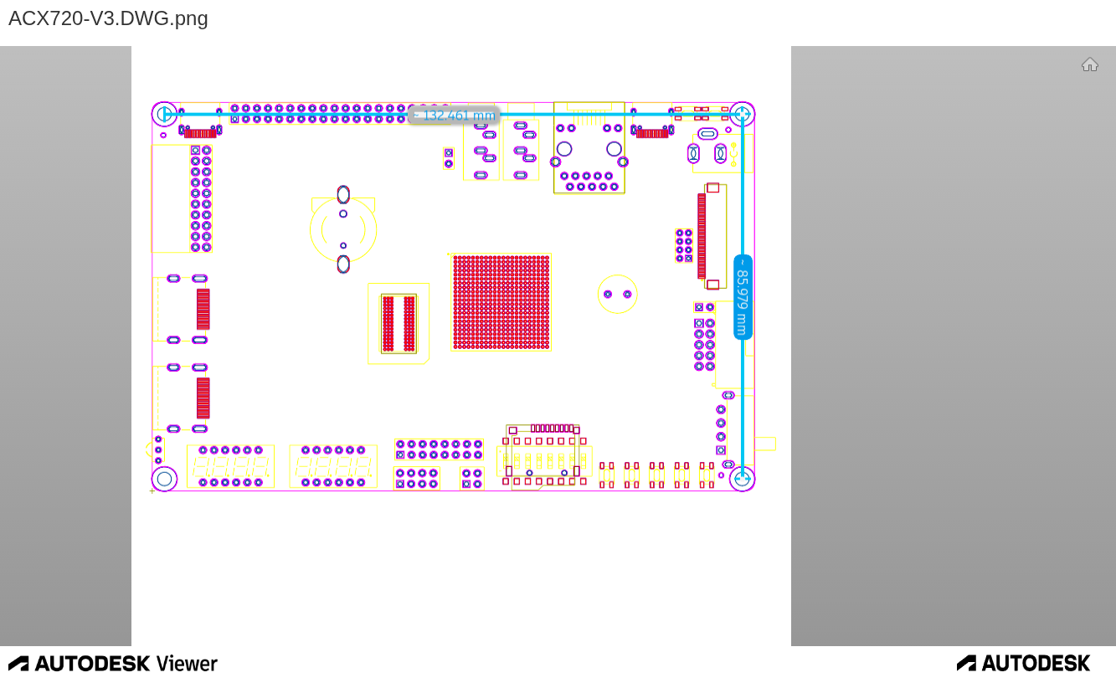
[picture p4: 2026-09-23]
model/EDE6B28DC4BC051CA18BC4B2684486C0.png

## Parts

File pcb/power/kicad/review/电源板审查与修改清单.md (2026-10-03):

# 电源板 KiCad 审查与封装同步记录

审查日期：2026-10-02。工程：`ProPrj_power_2026-10-02`，检查工具：KiCad CLI / Python API 10.0.5。

本次以用户最新确认的 **双路 AT8236 模块**为准。文档中的 DRV8874 是旧选型建议，不作为本板必须采用的器件。用户后续提供的资料图显示 MD-AT8236 V1.0 类接口，已确认模块标称参数、VCC 输入方向及 A/B 线序；模块原理图、孔中心距和实测电流仍缺。最新核对见 [AT8236 模块资料核对](../../../../doc/电机/AT8236模块资料核对.md)。

## 结论

现有图可以作为“两路独立 5V 降压＋双 AT8236 模块转接＋双编码电机接口”的设计基础，但**尚不能满足完整机器人电源板需求，也未达到投板条件**。

原理图已有清楚的功能分区，两路 Buck 的基本连接与 MP2236 引脚定义相符。两路都已画成 5V，预算中关于“旧 9V ACG720 支路”的描述不符合本次检查的这套工程。主要不足是 USB-C 源端保护、电池输入保护、动力急停与监测、3.3V 来源及 AT8236 模块的接口定义没有落实。图纸可读性也需要改善：`VCCOUT/VCCOUT1` 未标明分别给哪块计算板，接口只使用通用排针符号，缺少模块引脚功能和版本说明，导入产生了大量极短悬空线段。

本次完成了导入修复、封装绑定与原理图/PCB 对应。电源架构、保护器件及实际布线修改列为下一次电路改版工作，没有将未验证的模块或器件参数写成已确认的设计。

## 对照需求的判断

| 需求 | 现有实现 | 判断 |
| --- | --- | --- |
| 3S 电池，满电 12.6V | CN1 XT60 接 VCCIN | 输入电压的正常工作区间可覆盖；保护链不完整 |
| ACG720、Lichee Pi 分别取得 5V | U5→VCCOUT→USB1；U1→VCCOUT1→USB2 | 两路输出电气独立；具体板卡对应关系需标明，ACG720 供电口仍需核实 |
| 每个 USB-C 口支持约 3A | 两路 MP2236；各口 CC1/CC2 10kΩ 上拉 | 降压级有设计基础；端口没有连接检测和独立限流/反灌保护 |
| 双 MG513 电机与编码器 | 两组 AT8236 模块插接排针、J3/J4 六针电机接口 | 资料确认每块使用 A 通道、VCC 为输入、3.3V IN 电平相容；PCB J6/J8 排列与模块相反，排距需实测，限流/散热未验证 |
| 上电、复位、下载期间禁止运动 | 外接模块的 IN1/IN2 直接接控制接口 | 需落实硬件默认低电平及故障锁存；不能只依赖软件 |
| 急停硬件切断动力、保留计算电源 | SW2 将 VCCIN 接至 VM | 分支位置基本有此意图；小滑动开关不等于合适的动力急停方案 |
| 编码器、IMU、ToF 的 3.3V 支路 | 只有 /3.3V 网络，没有本板稳压源 | 供电来源未定义；已确认模块 VCC 是输入，应由本板稳压源或经过核实的 FPGA 电源提供 |
| 电池欠压、故障记录和受控关机 | 没有电池监测/告警/故障接口 | 未满足 |
| 两台步进电机，若继续纳入预算 | 没有完整绕组端子与恒流步进驱动连接 | 未实现；两块双路模块的剩余通道也不足以覆盖两台两相步进电机 |
| 三路 ToF 的功能需求 | 预算按一块 ToF，本板无明确传感器分配接口 | 需求与预算数量需统一 |

## 必须修改的电路和物料

### 1. 补齐电池保护和动力安全链

- CN1 到 VCCIN 之间没有主保险、防反接和明确的总开关/保护链。外接驱动模块即使自带防反接，也不能保护本板两路 Buck。
- SW2 `SS-12D10L5` 串在全部 VM 动力供电路径中。必须按两电机启动/限流电流及后续执行器负载核实其直流开断能力，优先用急停触点控制合适的直流接触器或大电流高边开关。
- 增加急停状态反馈、硬件禁止信号与默认下拉。急停解除、驱动过温恢复、通信恢复后，系统仍须保持未解锁，避免自动恢复运动。
- 增加电池单节保护/监测方案及低电量告警。现有 Buck EN 的 300kΩ/130kΩ 分压启停点约在 4V 附近，远低于 3S 正常保护区间，不能当作电池欠压保护。Linux 应留有受控关机时间。
- VM 侧没有本板的大容量储能电容。需核实模块已有电容，并在模块附近保留合适耐压的低 ESR 母线电容、旁路及回生吸收措施。

### 2. 补 USB-C 源端控制与每口保护

USB1/USB2 的 VBUS 目前直接连到各自 Buck 输出。R4/R5、R8/R9 的 10kΩ 上拉只表达 CC 电流宣告意图，没有检测接入设备后才打开 VBUS 的功能。应每口增加固定 5V 源端控制、限流/短路、放电和所需的反灌/过压保护。TPS25810 是文档中可继续评估的方案；反向阻断等功能必须逐项按所选器件确认，不能默认全部内置。[TI TPS25810 数据手册](https://www.ti.com/lit/ds/symlink/tps25810.pdf)

VBUS 和 GND 的两组并联触点在原理图中已正确接到同一网络。仍需核对当前插座 `LAIL-TYPE-C-16PIN-08-WT` 的真实 3A 额定、焊盘、开槽及外壳接地。ACG720 的 Type-C 是否给整板供电、允许电流、供电选择和与调试 USB 的隔离仍是前置条件。

### 3. 确认 AT8236 模块的通道和控制边界

这是外接模块方案，本次绑定的是模块插接排针，**没有在本板上添加 AT8236 裸芯片封装**。

- J5/J6 是一组模块排针，J7/J8 是另一组。资料确认 J5/J7 的输出是 AOUT，J6/J8 的 1、2 脚应分别对应 BOUT2/BOUT1，当前 NC。每块使用 A 通道、未用 B 输出不连接的方案成立。
- J5 同时出现 `LAOUT1/2` 和 `LBIN1/2`，J6 则出现 `LAIN1/2`；右侧同理。资料确认这种 A/B 跨两排分布是模块原有布局，原理图逻辑网络相符。**但 PCB 两排都按相同 X 方向排列 1→7；模块要求对排反向。J6/J8 需绕排针中心旋转 180°并重布线，或改为编号正确的整体模块封装。当前不能直接插模块上电。**
- 普通 AT8236 的 IN1/IN2 与 `LF_ENA/LF_ENB` 等编码器信号是不同用途，不要把编码器 ENA/ENB 当驱动使能。当前没有独立的全局使能/急停输入和驱动故障反馈。
- 资料给出模块 VM 5–17V、IN 0–5.25V、VCC 参考输入 0–4V、PWM 上限 100kHz、每路 3A 标称/6A 峰值。3.3V IN 高低电平与芯片条件相容。VCC 不得接 5V，也不能当成编码器电源输出；实际 VREF/ISEN 限流取决于模块实现。6A 在芯片手册绝对极限表中出现，不能作为持续堵转能力。[杭州中科微 AT8236 手册 V1.1（原厂资料镜像）](https://atta.szlcsc.com/upload/public/pdf/source/20210923/1552D95CBAF8BE780D06AE79E7783380.pdf)
- 当前 FPGA 文档仍采用 TB6612 的独立 PWM/STBY 接口，需适配为 AT8236 两个 IN 的 PWM 控制；不能只连接原有方向输出而丢弃 PWM。资料图真值表 00=滑行/休眠、10=正向、01=反向、11=制动。
- MG513 的 3.2A 堵转值来自项目中的电机资料，不能直接当作模块持续电流要求或设定值。实测启动、限流和温升后确定模块能力。
- 若两台两相步进电机都使用 AT8236 实现，需要每台两路 H 桥以及合适的恒流控制；与两台直流电机合计需要六路桥。现有两块双路模块合计四路，数量和接口均不足。

### 4. 明确 3.3V 的来源

当前 /3.3V 同时连接两组模块排针、控制板接口与编码器端子。资料已明确 VCC 为外部参考输入，**不能由该模块给此网络供电**。必须定义由本板稳压器还是经过能力核实的 FPGA 电源提供；本图仍缺板上 3.3V 稳压源。VCC 的内部参考连接和限流阻值需继续核实，固定 3.3V 并不自动对应 3A 限流。

按已确认来源补独立稳压/隔离和传感器分配接口，预算至少覆盖两编码器、IMU 及实际数量的 ToF。接电机前确认霍尔/GMR 版本、六针线序和编码器供电/输出电平。

### 5. 清理会造成错料的 BOM 字段

| 位号 | 图上数值 | 现有物料字段 | 需要处理 |
| --- | --- | --- | --- |
| R4/R5/R8/R9 | 10kΩ | `0603WAF5602T5E` / C23206，实际是 56kΩ | 按最终 USB-C 控制方案换正确阻值的物料，不能按当前编号贴装 |
| L1/L2 | 4.8µH | `MCS0630-2R2MPY1` / C2937096，描述为 2.2µH | 定下实际电感后统一 Value、型号和采购号，重新核算饱和/纹波/热损耗 |
| C7/C15 | 220pF | Description 仍写 100nF | 清理模板字段并确认补偿电容的介质、容差与型号 |
| C11/C16 | 1µF | Description 仍写 100nF | 清理模板字段并选择适用 0603 的真实器件 |
| C58 | 100µF / 0805 | 无明确采购号与耐压 | 确认能否在电池电压下取得所需有效容量；不能按标称容量代替储能设计 |
| U1/U5 等 | 有型号 | 部分字段缺有效 Datasheet / 未确定采购号 | 形成经过参数核对的可采购 BOM |

`0603WAF5602T5E` 的 56kΩ 属性也可在[安森美公开 BOM](https://www.onsemi.com/download/eval-board-bom/pdf/led-smart-dim-llc-150wgevb_bom_rohs.pdf)中交叉核对。这里保留冲突以便追踪，没有把未确定的新料号编入工程。

### 6. 保留两路 Buck 的基础，复核瞬态保护与热设计

两路 `82kΩ/11.1kΩ` 反馈分压按 0.6V 典型基准计算：`0.6 × (1 + 82 / 11.1) ≈ 5.03V`。这是设定值估算，不是板端带载结果。MP2236 的正常输入上限为 18V，绝对最大值为 20V；电池正常电压可覆盖，但电机回生尖峰需要单独处理。[MPS MP2236 数据手册](https://www.monolithicpower.com/en/documentview/productdocument/index/version/2/document_type/Datasheet/lang/en/sku/MP2236/document_id/4411/)

D1 是安邦 `SMF12A`，接在 VM 而非 Buck 直接取电的 VCCIN。需取得此具体器件手册核实其反向工作电压与动态钳位。作为同型号的参数示例，Littelfuse SMF12A 的反向工作电压为 12V、指定脉冲钳位为 19.9V；前者低于满电 12.6V，后者已靠近 MP2236 绝对最大值，且线路寄生还会增加尖峰。**不能把旧建议中的 SMBJ15A 不加核算地替换进来**，应共同选择 TVS、吸收/过压关断及 Buck 耐压。[Littelfuse SMF 系列手册](https://www.littelfuse.com/~/media/electronics/datasheets/tvs_diodes/littelfuse_tvs_diode_smf_datasheet.pdf.pdf)

器件额定电流不保证现有两层板的输出能力。需按每口实际 3A、动力启动电流、铜厚、过孔及连接器能力核算温升，并测试两口带载、电机换向、低电量和插拔时的电压。

## 本次已经完成的修改

1. 53 个物理元件全部通过原理图 UUID 与 PCB `path` 关联；逐项核对 189 个引脚/焊盘编号与网络。
2. 将原 PCB 的 `$1N...` 和不带层级路径的标签网络，通过相同位号/焊盘的连接对应到 KiCad 原理图网络；共核对 39 个原有非空网络映射。原理图电气连通关系保持一致。
3. 新增项目本地 `ProPrj_pow-easyedapro.pretty` 与 `fp-lib-table`，共 23 个封装文件。包含 14 类基础封装及 9 个保留原导入图形细节的实例变体；没有因统一库文件而移动焊盘。当前已无封装库缺失和封装副本不匹配告警。
4. C6/C7/C11/C14/C15/C16 从原理图的 0805 绑定改为 PCB 已有的 0603，且它们的 Supplier Footprint 原本也标为 0603。其容值/采购确认仍见上表。
5. 118 个 `thru_hole + 0.001mm 钻孔` 假通孔改为真实 SMD，层改为 `F.Cu/F.Paste/F.Mask`。USB 外壳真实槽孔及排针通孔保留。原先五处由假通孔触碰底层走线造成的短路告警已消除。
6. 四个无位号 3mm 固定孔设为 H1–H4、NPTH，并排除 BOM/贴装。图框排除板上器件与 BOM；35 个电源符号补齐位号。
7. 修复电阻、电容、连接器等被导入为 Input/Unspecified 的电气类型，并按 MP2236 手册配置电源和控制引脚类型。修复电源符号缓存/本地库对应，补 PCB 数值及元件属性，LED 补通用 Value。
8. 使用 KiCad 原生功能重填九个实际铜皮区。原导入另含 97 个自动泪滴缓存区，原生重填时被清理；重新布线时应按焊盘和过孔设置生成泪滴。原始缓存仍在备份中。

元件位置、焊盘位置/尺寸及既有 337 段走线、23 个过孔的几何均通过修改前后对比。PCB 依然是原来的两层 100×50mm 布局。本次封装绑定成功只证明项目库、编号和网络一致，不代表特定模块的机械尺寸已经验证。

### 接口位号对照

| 原位号 | 现位号 | 用途 |
| --- | --- | --- |
| L | J1 | 左侧控制/编码器接口 |
| R | J2 | 右侧控制/编码器接口 |
| 左电机 | J3 | 左电机六针接口 |
| 右电机 | J4 | 右电机六针接口 |
| U2 / U3 | J5 / J6 | 第一组 AT8236 模块两排插接接口 |
| U4 / U6 | J7 / J8 | 第二组 AT8236 模块两排插接接口 |

四个 7 针接口本身针距为 2.54mm。当前 PCB 中 J5–J6 两排中心距为 **23.0005mm**，J7–J8 为 **23.1275mm**，且同侧两排编号均按同一 X 方向递增。资料的 23mm 是外形长边，不能作为孔中心距；目前排距与图中孔位位于板内的情况不相符，两组也不一致。资料确认两排必须反向编号，因此 J6/J8 的排列需修改；具体排距需实物测量。核对证据见 `at8236-interface-audit.json`，当前原理图重新导出后 J1–J8 的 56 个引脚/焊盘网络一致，但不能据此证明模块能正确插接。

## 检查结果与 PCB 待修改项

| 检查 | 修改前 | 修改后 |
| --- | ---: | ---: |
| ERC | 230：22 错误＋208 警告 | 36：4 错误＋32 警告 |
| DRC 一般违规 | 543：479 错误＋64 警告 | 89：77 错误＋12 警告 |
| PCB 未连接项目，另计 | 0 | 9 |
| 原理图/PCB 一致性问题，另计 | 224 | **0** |

修改前“0 未连接”受假通孔及导入铜皮缓存影响，不能作为电源走线正确的证明。修正焊盘后出现的 9 项才是当前检查需要处理的断连；同一区域的错误可能有多个描述，不代表九条独立物理断线。

剩余 ERC：四条电源输入未被电源输出驱动，需按真实电源来源补正确标志；32 条极短线段的悬空端点警告，需整理图形。**不要通过随意添加 PWR_FLAG 把缺少的实际电源掩盖掉。**

剩余 DRC：48 间距、17 热焊盘连接不足、9 铜到板边间距、3 courtyard 重叠、8 丝印到板边、4 丝印压铜。没有降低项目规则，也没有新增规则排除来消除这些结果；报告沿用工程已有规则及已有 ignored_checks。

优先处理的 PCB 区域：

- **U1/U5 GND**：输出功率地存在真实断连，先连接正确地回流，不能仅靠模拟通孔或孤岛铜皮。
- **U1 VIN、C9 与输入铜皮**：重新接通输入回路，检查热焊盘连接和狭窄铜颈。
- **L1→C4/C5、L2→C12/C13**：两个输出网络存在铜皮岛及断连，重新布通各自输出路径。
- **D1/R15/LED1/SW2**：封装 courtyard 重叠，需重新布局并核实实物装配空间。
- **USB1/USB2**：封装内有 Edge.Cuts 开槽图形，导致多条铜到板边不足。按所用插座尺寸图复核槽口，不能未经依据删除开槽或把违规一律忽略。
- **CN1**：4 号焊盘到外边缘约 0.397mm，小于当前 0.5mm 约束；调整入口位置或明确制造能力后合理设定规则。
- **大电流路径**：现有线宽以 0.254/0.508/0.762mm 为主，必须逐网核查 VCCIN、VM、两路 5V 与电机输出；不能据此直接宣称达到预算里的 20A 短时目标。

## 文件与复查入口

- 可编辑工程：本目录上一层的 `.kicad_pro/.kicad_sch/.kicad_pcb`。
- `component-map.json`：元件、原位号、封装及原理图/PCB UUID。
- `pin-map.csv`：189 个引脚/焊盘对应的完整网络表。
- `verification.json`：网络连通、几何保留及规则检查汇总。
- `before-erc.json/before-drc.json`、`after-erc.json/after-drc.json`：KiCad 原生检查报告。
- `repair-backups/`：修改前工程和库的本地备份，已被项目的 `*-backups/` 忽略规则排除。
- 修复脚本是本次导入的一次性操作记录，**不要在后续手工改图后重新执行 `repair_import.py prepare`**，它会从修改前备份重新生成原理图。

建议改版顺序：先修正 AT8236 对排排列、实测排距和限流并明确 3.3V 来源，适配 FPGA 驱动接口，确定动力急停与 USB-C 源端，再清理采购字段和布局布线。完成 ERC/DRC 后，以限流电源和电子负载分支上电，最后接计算板和电机，实测欠压、短路、急停、换向、温升及反灌。

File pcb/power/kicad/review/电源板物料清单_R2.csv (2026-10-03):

位号 | 数量 | 规格与用途 | 型号 | KiCad封装 | 采购核对事项 | 安装位置 | 采购链接 | 保险座参考链接
C1,C2,C3,C4,C5,C8,C9,C10,C12,C13 | 10 | 22uF 25V X5R |  | Capacitor_SMD:C_0805_2012Metric | 核对实际外形、焊盘、额定值及温升；无完整采购料号的物料尚未定型 | 板上
C6,C14,C109 | 3 | 100nF 50V |  | Capacitor_SMD:C_0603_1608Metric | 核对实际外形、焊盘、额定值及温升；无完整采购料号的物料尚未定型 | 板上
C7,C15 | 2 | 220pF C0G |  | Capacitor_SMD:C_0603_1608Metric | 核对实际外形、焊盘、额定值及温升；无完整采购料号的物料尚未定型 | 板上
C11,C16,C104,C106 | 4 | 1uF 25V |  | Capacitor_SMD:C_0805_2012Metric | 核对实际外形、焊盘、额定值及温升；无完整采购料号的物料尚未定型 | 板上
C58 | 1 | 470uF 35V 低等效串联电阻 |  | Capacitor_THT:CP_Radial_D10.0mm_P5.00mm | 核对实际外形、焊盘、额定值及温升；无完整采购料号的物料尚未定型 | 板上
C59 | 1 | 10uF 50V |  | Capacitor_SMD:C_0805_2012Metric | 核对实际外形、焊盘、额定值及温升；无完整采购料号的物料尚未定型 | 板上
C60,C102,C103,C113,C114,C115,C116,C117,C118,C119,C120,C121,C123,C124,C127,C130,C132,C133,C138,C139,C140,C141,C142 | 23 | 100nF 50V |  | Capacitor_SMD:C_0805_2012Metric | 核对实际外形、焊盘、额定值及温升；无完整采购料号的物料尚未定型 | 板上
C101 | 1 | 100uF 25V |  | Capacitor_THT:CP_Radial_D10.0mm_P5.00mm | 核对实际外形、焊盘、额定值及温升；无完整采购料号的物料尚未定型 | 板上
C105,C107 | 2 | 4.7uF 10V X7R |  | Capacitor_SMD:C_0805_2012Metric | 核对实际外形、焊盘、额定值及温升；无完整采购料号的物料尚未定型 | 板上
C108 | 1 | 10uF 25V |  | Capacitor_SMD:C_0805_2012Metric | 核对实际外形、焊盘、额定值及温升；无完整采购料号的物料尚未定型 | 板上
C110,C111 | 2 | 22uF 10V X7R |  | Capacitor_SMD:C_0805_2012Metric | 核对实际外形、焊盘、额定值及温升；无完整采购料号的物料尚未定型 | 板上
C112 | 1 | 10uF 10V X7R |  | Capacitor_SMD:C_0805_2012Metric | 核对实际外形、焊盘、额定值及温升；无完整采购料号的物料尚未定型 | 板上
C122,C131 | 2 | 470uF 25V 低等效串联电阻 |  | Capacitor_THT:CP_Radial_D10.0mm_P5.00mm | 核对实际外形、焊盘、额定值及温升；无完整采购料号的物料尚未定型 | 板上
C125,C126,C134,C135 | 4 | 1uF 25V |  | Capacitor_SMD:C_0603_1608Metric | 核对实际外形、焊盘、额定值及温升；无完整采购料号的物料尚未定型 | 板上
C128,C129,C136,C137 | 4 | 1nF C0G |  | Capacitor_SMD:C_0603_1608Metric | 核对实际外形、焊盘、额定值及温升；无完整采购料号的物料尚未定型 | 板上
C143 | 1 | 100nF 25V |  | Capacitor_SMD:C_0603_1608Metric | 核对实际外形、焊盘、额定值及温升；无完整采购料号的物料尚未定型 | 板上
CN1 | 1 | XT60PW-M / 三串电池 |  | Connector_AMASS:AMASS_XT60PW-M_1x02_P7.20mm_Horizontal | 核对实际外形、焊盘、额定值及温升；无完整采购料号的物料尚未定型 | 板上
D1 | 1 | SMBJ15CA | SMBJ15CA | Diode_SMD:D_SMB | 核对实际外形、焊盘、额定值及温升；无完整采购料号的物料尚未定型 | 板上
D2,D3,D4,D5,D6,D7,D8 | 7 | BZT52C12 |  | Diode_SMD:D_SOD-123 | 核对实际外形、焊盘、额定值及温升；无完整采购料号的物料尚未定型 | 板上
F1 | 1 | MINI汽车插片保险丝10A/32VDC；初值须实测；保险座四孔9.92×3.40mm、钻孔1.78mm | 0297010.J | Fuse:Fuseholder_Blade_Mini_Keystone_3568 | 板载MINI总保险；保险片为集电通0297010.J/C55117678，10A初值待实测；保险座为3568四孔式，孔距9.92×3.40mm、钻孔1.78mm，保险片与座分别采购；国产同孔位兼容座待核对；01530008.J未确认兼容，勿直接套用 | 板上，XT60正极之后、防反接管之前 | https://www.lcsc.com/pt/product-detail/C55117678.html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 | https://www.digikey.cn/zh/products/detail/keystone-electronics/3568/2137306
FB1 | 1 | 220Ω@100MHz / 1A |  | Inductor_SMD:L_0805_2012Metric | 核对实际外形、焊盘、额定值及温升；无完整采购料号的物料尚未定型 | 板上
J1 | 1 | 左轮控制 |  | Connector_PinHeader_2.54mm:PinHeader_1x08_P2.54mm_Vertical | 核对实际外形、焊盘、额定值及温升；无完整采购料号的物料尚未定型 | 板上
J2 | 1 | 右轮控制 |  | Connector_PinHeader_2.54mm:PinHeader_1x08_P2.54mm_Vertical | 核对实际外形、焊盘、额定值及温升；无完整采购料号的物料尚未定型 | 板上
J3,J4 | 2 | MG513电机 / 核对线序 |  | Connector_JST:JST_XH_B6B-XH-A_1x06_P2.50mm_Vertical | 核对实际外形、焊盘、额定值及温升；无完整采购料号的物料尚未定型 | 板上
J9 | 1 | 可选逻辑板3.3V输入 |  | Connector_PinHeader_2.54mm:PinHeader_1x02_P2.54mm_Vertical | 核对实际外形、焊盘、额定值及温升；无完整采购料号的物料尚未定型 | 板上
J10 | 1 | 惯性传感器电源 |  | Connector_JST:JST_PH_B2B-PH-K_1x02_P2.00mm_Vertical | 核对实际外形、焊盘、额定值及温升；无完整采购料号的物料尚未定型 | 板上
J11 | 1 | 测距传感器1电源 |  | Connector_JST:JST_PH_B2B-PH-K_1x02_P2.00mm_Vertical | 核对实际外形、焊盘、额定值及温升；无完整采购料号的物料尚未定型 | 板上
J12 | 1 | 测距传感器2电源 |  | Connector_JST:JST_PH_B2B-PH-K_1x02_P2.00mm_Vertical | 核对实际外形、焊盘、额定值及温升；无完整采购料号的物料尚未定型 | 板上
J13 | 1 | 测距传感器3电源 |  | Connector_JST:JST_PH_B2B-PH-K_1x02_P2.00mm_Vertical | 核对实际外形、焊盘、额定值及温升；无完整采购料号的物料尚未定型 | 板上
J14 | 1 | 3.3V辅助输出 |  | TerminalBlock_Phoenix:TerminalBlock_Phoenix_MKDS-1,5-2-5.08_1x02_P5.08mm_Horizontal | 核对实际外形、焊盘、额定值及温升；无完整采购料号的物料尚未定型 | 板上
J15 | 1 | 急停常闭回路 |  | TerminalBlock_Phoenix:TerminalBlock_Phoenix_MKDS-1,5-2-5.08_1x02_P5.08mm_Horizontal | 核对实际外形、焊盘、额定值及温升；无完整采购料号的物料尚未定型 | 板上
J16 | 1 | 左回生泄放 / 外接3.3Ω |  | TerminalBlock_Phoenix:TerminalBlock_Phoenix_MKDS-1,5-2-5.08_1x02_P5.08mm_Horizontal | 核对实际外形、焊盘、额定值及温升；无完整采购料号的物料尚未定型 | 板上
J17 | 1 | 右回生泄放 / 外接3.3Ω |  | TerminalBlock_Phoenix:TerminalBlock_Phoenix_MKDS-1,5-2-5.08_1x02_P5.08mm_Horizontal | 核对实际外形、焊盘、额定值及温升；无完整采购料号的物料尚未定型 | 板上
J18 | 1 | 电源监测 / 外部模数转换 |  | Connector_PinHeader_2.54mm:PinHeader_1x12_P2.54mm_Vertical | 核对实际外形、焊盘、额定值及温升；无完整采购料号的物料尚未定型 | 板上
JP1 | 1 | 1-2板载 / 2-3逻辑板 |  | Connector_PinHeader_2.54mm:PinHeader_1x03_P2.54mm_Vertical | 核对实际外形、焊盘、额定值及温升；无完整采购料号的物料尚未定型 | 板上
L1,L2,L3 | 3 | 4.7uH FXL0630-4R7-M | FXL0630-4R7-M | Inductor_SMD:L_Changjiang_FXL0630 | 4.7µH±20%；最大直流电阻33mΩ；额定温升电流6A；核对具体温升/饱和定义 | 板上
Q1,Q2,Q3 | 3 | IRF4905 | IRF4905 | Package_TO_SOT_THT:TO-220-3_Vertical | 核对实际外形、焊盘、额定值及温升；无完整采购料号的物料尚未定型 | 板上
Q4,Q5,Q9,Q11,Q13 | 5 | MMBT3904 | MMBT3904 | Package_TO_SOT_SMD:SOT-23 | 核对实际外形、焊盘、额定值及温升；无完整采购料号的物料尚未定型 | 板上
Q6,Q7 | 2 | IRLZ44N | IRLZ44N | Package_TO_SOT_THT:TO-220-3_Vertical | 核对实际外形、焊盘、额定值及温升；无完整采购料号的物料尚未定型 | 板上
Q8,Q10 | 2 | AO4409 | AO4409 | Package_SO:SOIC-8_3.9x4.9mm_P1.27mm | 核对实际外形、焊盘、额定值及温升；无完整采购料号的物料尚未定型 | 板上
Q12 | 1 | AO3401A | AO3401A | Package_TO_SOT_SMD:SOT-23 | 核对实际外形、焊盘、额定值及温升；无完整采购料号的物料尚未定型 | 板上
R1,R6 | 2 | 10R |  | Resistor_SMD:R_0603_1608Metric | 核对实际外形、焊盘、额定值及温升；无完整采购料号的物料尚未定型 | 板上
R2,R11 | 2 | 82.5k 0.1% |  | Resistor_SMD:R_0603_1608Metric | 核对实际外形、焊盘、额定值及温升；无完整采购料号的物料尚未定型 | 板上
R3,R12 | 2 | 11.0k 0.1% |  | Resistor_SMD:R_0603_1608Metric | 核对实际外形、焊盘、额定值及温升；无完整采购料号的物料尚未定型 | 板上
R51,R87,R97 | 3 | 100k |  | Resistor_SMD:R_0603_1608Metric | 核对实际外形、焊盘、额定值及温升；无完整采购料号的物料尚未定型 | 板上
R52 | 1 | 2.2k |  | Resistor_SMD:R_0603_1608Metric | 核对实际外形、焊盘、额定值及温升；无完整采购料号的物料尚未定型 | 板上
R53,R59,R64,R66,R68,R69,R70,R71,R72,R74,R88,R89,R91,R93,R98,R99,R101,R103,R106,R111,R118,R121 | 22 | 10k |  | Resistor_SMD:R_0603_1608Metric | 核对实际外形、焊盘、额定值及温升；无完整采购料号的物料尚未定型 | 板上
R54,R73,R75,R78,R82,R108,R113,R117 | 8 | 4.7k |  | Resistor_SMD:R_0603_1608Metric | 核对实际外形、焊盘、额定值及温升；无完整采购料号的物料尚未定型 | 板上
R55 | 1 | 26.1k 0.1% |  | Resistor_SMD:R_0603_1608Metric | 核对实际外形、焊盘、额定值及温升；无完整采购料号的物料尚未定型 | 板上
R56,R58,R61,R63,R77,R81,R105,R110,R115,R120,R123 | 11 | 10.0k 0.1% |  | Resistor_SMD:R_0603_1608Metric | 核对实际外形、焊盘、额定值及温升；无完整采购料号的物料尚未定型 | 板上
R57,R62 | 2 | 46.4k 0.1% |  | Resistor_SMD:R_0603_1608Metric | 核对实际外形、焊盘、额定值及温升；无完整采购料号的物料尚未定型 | 板上
R60 | 1 | 28.7k 0.1% |  | Resistor_SMD:R_0603_1608Metric | 核对实际外形、焊盘、额定值及温升；无完整采购料号的物料尚未定型 | 板上
R65,R67 | 2 | 150k 1% |  | Resistor_SMD:R_0603_1608Metric | 核对实际外形、焊盘、额定值及温升；无完整采购料号的物料尚未定型 | 板上
R76,R80 | 2 | 51.1k 0.1% |  | Resistor_SMD:R_0603_1608Metric | 核对实际外形、焊盘、额定值及温升；无完整采购料号的物料尚未定型 | 板上
R79,R83 | 2 | 1M |  | Resistor_SMD:R_0603_1608Metric | 核对实际外形、焊盘、额定值及温升；无完整采购料号的物料尚未定型 | 板上
R84,R94 | 2 | 0.020R 1% 1W |  | Resistor_SMD:R_2512_6332Metric | 核对实际外形、焊盘、额定值及温升；无完整采购料号的物料尚未定型 | 板上
R85,R86,R95,R96,R107,R112,R116 | 7 | 1k |  | Resistor_SMD:R_0603_1608Metric | 核对实际外形、焊盘、额定值及温升；无完整采购料号的物料尚未定型 | 板上
R90,R92,R100,R102 | 4 | 100R |  | Resistor_SMD:R_0603_1608Metric | 核对实际外形、焊盘、额定值及温升；无完整采购料号的物料尚未定型 | 板上
R104,R109 | 2 | 11.5k 0.1% |  | Resistor_SMD:R_0603_1608Metric | 核对实际外形、焊盘、额定值及温升；无完整采购料号的物料尚未定型 | 板上
R114 | 1 | 3.83k 0.1% |  | Resistor_SMD:R_0603_1608Metric | 核对实际外形、焊盘、额定值及温升；无完整采购料号的物料尚未定型 | 板上
R119 | 1 | 30.9k 0.1% |  | Resistor_SMD:R_0603_1608Metric | 核对实际外形、焊盘、额定值及温升；无完整采购料号的物料尚未定型 | 板上
R122 | 1 | 10.5k 0.1% |  | Resistor_SMD:R_0603_1608Metric | 核对实际外形、焊盘、额定值及温升；无完整采购料号的物料尚未定型 | 板上
R124 | 1 | 100k 0.1% |  | Resistor_SMD:R_0603_1608Metric | 核对实际外形、焊盘、额定值及温升；无完整采购料号的物料尚未定型 | 板上
R125 | 1 | 27.4k 0.1% |  | Resistor_SMD:R_0603_1608Metric | 核对实际外形、焊盘、额定值及温升；无完整采购料号的物料尚未定型 | 板上
RV1,RV2 | 2 | 10k 3296W / VREF | 3296W-1-103LF | Potentiometer_THT:Potentiometer_Bourns_3296W_Vertical | 核对实际外形、焊盘、额定值及温升；无完整采购料号的物料尚未定型 | 板上
TP1 | 1 | 电机总开关输出 |  | TestPoint:TestPoint_Pad_D2.0mm | 核对实际外形、焊盘、额定值及温升；无完整采购料号的物料尚未定型 | 板上
U1,U5 | 2 | MP2236GJ-Z | MP2236GJ-Z | Package_TO_SOT_SMD:TSOT-23-8 | 核对实际外形、焊盘、额定值及温升；无完整采购料号的物料尚未定型 | 板上
U2 | 1 | AT8236双路模块 | AT8236 dual module / vendor-specific | EdgeMind_Module:AT8236_Dual_PinSocket_2x7_P2.54_Row23.0005mm | 双路AT8236模块；测采样电阻并校准；排距沿用旧PCB，仍须试插 | 板上
U3 | 1 | AP63203WU-7 | AP63203WU-7 | Package_TO_SOT_SMD:TSOT-23-6 | 核对实际外形、焊盘、额定值及温升；无完整采购料号的物料尚未定型 | 板上
U4 | 1 | AT8236双路模块 | AT8236 dual module / vendor-specific | EdgeMind_Module:AT8236_Dual_PinSocket_2x7_P2.54_Row23.1275mm | 双路AT8236模块；测采样电阻并校准；排距沿用旧PCB，仍须试插 | 板上
U7,U8 | 2 | HUSB305-02 | HUSB305-02 | Package_TO_SOT_SMD:TSOT-23-8 | 必须为-02版、TSOT-23-8；不可误购DFN版本；准确采购代码与单价待确认 | 板上
U10,U11 | 2 | 74HC08D | SN74HC08DR | Package_SO:SOIC-14_3.9x8.7mm_P1.27mm | 核对实际外形、焊盘、额定值及温升；无完整采购料号的物料尚未定型 | 板上
U12 | 1 | 74HC74D | SN74HC74DR | Package_SO:SOIC-14_3.9x8.7mm_P1.27mm | 核对实际外形、焊盘、额定值及温升；无完整采购料号的物料尚未定型 | 板上
U13 | 1 | MCP100-300DI/TO | MCP100-300DI/TO | Package_TO_SOT_THT:TO-92_Inline | 核对实际外形、焊盘、额定值及温升；无完整采购料号的物料尚未定型 | 板上
U21 | 1 | TL431BIDBZR | TL431BIDBZR | Package_TO_SOT_SMD:SOT-23 | 核对实际外形、焊盘、额定值及温升；无完整采购料号的物料尚未定型 | 板上
U22,U23,U24,U27,U28,U29,U30 | 7 | LM393BIDR | LM393BIDR | Package_SO:SOIC-8_3.9x4.9mm_P1.27mm | 核对实际外形、焊盘、额定值及温升；无完整采购料号的物料尚未定型 | 板上
U25,U26 | 2 | INA180A1IDBVR | INA180A1IDBVR | Package_TO_SOT_SMD:SOT-23-5 | 核对实际外形、焊盘、额定值及温升；无完整采购料号的物料尚未定型 | 板上
USB1,USB2 | 2 | USB4125-GF-A / 六针供电 | USB4125-GF-A | Connector_USB:USB_C_Receptacle_GCT_USB4125-xx-x_6P_TopMnt_Horizontal | 普通1.0mm定位柱版六针供电口；不可混用-0190加长定位柱版 | 板上

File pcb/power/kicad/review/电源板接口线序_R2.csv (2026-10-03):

接口位号 | 用途 | 引脚编号 | 网络或功能
CN1 | XT60PW-M / 三串电池 | 1 | GND
CN1 | XT60PW-M / 三串电池 | 2 | BAT_POS
J1 | 左轮控制 | 1 | L_PWM_FWD_RAW
J1 | 左轮控制 | 2 | L_PWM_REV_RAW
J1 | 左轮控制 | 3 | MOTOR_ARM
J1 | 左轮控制 | 4 | MOTOR_PERMIT
J1 | 左轮控制 | 5 | GND
J1 | 左轮控制 | 6 | 3V3_FPGA_IN
J1 | 左轮控制 | 7 | ENC_L_A_FPGA
J1 | 左轮控制 | 8 | ENC_L_B_FPGA
J2 | 右轮控制 | 1 | ENC_R_B_FPGA
J2 | 右轮控制 | 2 | ENC_R_A_FPGA
J2 | 右轮控制 | 3 | 3V3_FPGA_IN
J2 | 右轮控制 | 4 | GND
J2 | 右轮控制 | 5 | R_PWM_FWD_RAW
J2 | 右轮控制 | 6 | R_PWM_REV_RAW
J2 | 右轮控制 | 7 | EXT_KILL_N
J2 | 右轮控制 | 8 | MOTOR_ARMED
J3 | MG513电机 / 核对线序 | 1 | Net-(J3-Pin_1)
J3 | MG513电机 / 核对线序 | 2 | +3V3
J3 | MG513电机 / 核对线序 | 3 | ENC_L_A
J3 | MG513电机 / 核对线序 | 4 | ENC_L_B
J3 | MG513电机 / 核对线序 | 5 | GND
J3 | MG513电机 / 核对线序 | 6 | Net-(J3-Pin_6)
J4 | MG513电机 / 核对线序 | 1 | Net-(J4-Pin_1)
J4 | MG513电机 / 核对线序 | 2 | +3V3
J4 | MG513电机 / 核对线序 | 3 | ENC_R_A
J4 | MG513电机 / 核对线序 | 4 | ENC_R_B
J4 | MG513电机 / 核对线序 | 5 | GND
J4 | MG513电机 / 核对线序 | 6 | Net-(J4-Pin_6)
J9 | 可选逻辑板3.3V输入 | 1 | 3V3_FPGA_IN
J9 | 可选逻辑板3.3V输入 | 2 | GND
J10 | 惯性传感器电源 | 1 | +3V3_SENS
J10 | 惯性传感器电源 | 2 | GND
J11 | 测距传感器1电源 | 1 | +3V3_SENS
J11 | 测距传感器1电源 | 2 | GND
J12 | 测距传感器2电源 | 1 | +3V3_SENS
J12 | 测距传感器2电源 | 2 | GND
J13 | 测距传感器3电源 | 1 | +3V3_SENS
J13 | 测距传感器3电源 | 2 | GND
J14 | 3.3V辅助输出 | 1 | +3V3
J14 | 3.3V辅助输出 | 2 | GND
J15 | 急停常闭回路 | 1 | +3V3
J15 | 急停常闭回路 | 2 | ESTOP_OK
J16 | 左回生泄放 / 外接3.3Ω | 1 | VM_L
J16 | 左回生泄放 / 外接3.3Ω | 2 | Net-(J16-Pin_2)
J17 | 右回生泄放 / 外接3.3Ω | 1 | VM_R
J17 | 右回生泄放 / 外接3.3Ω | 2 | Net-(J17-Pin_2)
J18 | 电源监测 / 外部模数转换 | 1 | +3V3
J18 | 电源监测 / 外部模数转换 | 10 | USB2_FAULT_PULSE_N
J18 | 电源监测 / 外部模数转换 | 11 | ESTOP_OK
J18 | 电源监测 / 外部模数转换 | 12 | POR_OK
J18 | 电源监测 / 外部模数转换 | 2 | GND
J18 | 电源监测 / 外部模数转换 | 3 | BAT_ADC
J18 | 电源监测 / 外部模数转换 | 4 | BAT_WARN_N
J18 | 电源监测 / 外部模数转换 | 5 | VM_L_IMON
J18 | 电源监测 / 外部模数转换 | 6 | VM_R_IMON
J18 | 电源监测 / 外部模数转换 | 7 | MOTOR_POWER_OK
J18 | 电源监测 / 外部模数转换 | 8 | MOTOR_ARMED
J18 | 电源监测 / 外部模数转换 | 9 | USB1_FAULT_PULSE_N
JP1 | 1-2板载 / 2-3逻辑板 | 1 | +3V3_ONBOARD
JP1 | 1-2板载 / 2-3逻辑板 | 2 | +3V3
JP1 | 1-2板载 / 2-3逻辑板 | 3 | 3V3_FPGA_IN
U2 | AT8236双路模块 | 1 | Net-(J3-Pin_1)
U2 | AT8236双路模块 | 10 | VREF_L
U2 | AT8236双路模块 | 11 | Net-(U2-AIN2)
U2 | AT8236双路模块 | 12 | Net-(U2-AIN1)
U2 | AT8236双路模块 | 13 | unconnected-(U2-BOUT1-Pad13)
U2 | AT8236双路模块 | 14 | unconnected-(U2-BOUT2-Pad14)
U2 | AT8236双路模块 | 2 | Net-(J3-Pin_6)
U2 | AT8236双路模块 | 3 | GND
U2 | AT8236双路模块 | 4 | GND
U2 | AT8236双路模块 | 5 | VREF_L
U2 | AT8236双路模块 | 6 | VM_L
U2 | AT8236双路模块 | 7 | GND
U2 | AT8236双路模块 | 8 | GND
U2 | AT8236双路模块 | 9 | VM_L
U4 | AT8236双路模块 | 1 | Net-(J4-Pin_1)
U4 | AT8236双路模块 | 10 | VREF_R
U4 | AT8236双路模块 | 11 | Net-(U4-AIN2)
U4 | AT8236双路模块 | 12 | Net-(U4-AIN1)
U4 | AT8236双路模块 | 13 | unconnected-(U4-BOUT1-Pad13)
U4 | AT8236双路模块 | 14 | unconnected-(U4-BOUT2-Pad14)
U4 | AT8236双路模块 | 2 | Net-(J4-Pin_6)
U4 | AT8236双路模块 | 3 | GND
U4 | AT8236双路模块 | 4 | GND
U4 | AT8236双路模块 | 5 | VREF_R
U4 | AT8236双路模块 | 6 | VM_R
U4 | AT8236双路模块 | 7 | GND
U4 | AT8236双路模块 | 8 | GND
U4 | AT8236双路模块 | 9 | VM_R
USB1 | USB4125-GF-A / 六针供电 | A12 | GND
USB1 | USB4125-GF-A / 六针供电 | A5 | Net-(U7-CC1)
USB1 | USB4125-GF-A / 六针供电 | A9 | USB1_VBUS
USB1 | USB4125-GF-A / 六针供电 | B12 | GND
USB1 | USB4125-GF-A / 六针供电 | B5 | Net-(U7-CC2)
USB1 | USB4125-GF-A / 六针供电 | B9 | USB1_VBUS
USB1 | USB4125-GF-A / 六针供电 | SH | GND
USB2 | USB4125-GF-A / 六针供电 | A12 | GND
USB2 | USB4125-GF-A / 六针供电 | A5 | Net-(U8-CC1)
USB2 | USB4125-GF-A / 六针供电 | A9 | USB2_VBUS
USB2 | USB4125-GF-A / 六针供电 | B12 | GND
USB2 | USB4125-GF-A / 六针供电 | B5 | Net-(U8-CC2)
USB2 | USB4125-GF-A / 六针供电 | B9 | USB2_VBUS
USB2 | USB4125-GF-A / 六针供电 | SH | GND

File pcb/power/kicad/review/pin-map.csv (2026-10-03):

Reference | Pin/Pad | Net | Footprint | SchematicUUID | PCB_UUID
C1 | 1 | GND | ProPrj_pow-easyedapro:C0805 | 9532639a-192f-4387-9e30-d6a73039d06c | 0df21acf-8c04-4aea-ac9e-fe96935ed2fa
C1 | 2 | VCCIN | ProPrj_pow-easyedapro:C0805 | 9532639a-192f-4387-9e30-d6a73039d06c | 0df21acf-8c04-4aea-ac9e-fe96935ed2fa
C2 | 1 | GND | ProPrj_pow-easyedapro:C0805 | 7f2cbcad-14d4-4bbe-b2f9-b1617291b055 | c0a39133-b87a-4211-b177-444096d060e8
C2 | 2 | VCCIN | ProPrj_pow-easyedapro:C0805 | 7f2cbcad-14d4-4bbe-b2f9-b1617291b055 | c0a39133-b87a-4211-b177-444096d060e8
C3 | 1 | GND | ProPrj_pow-easyedapro:C0805 | 23087e86-c8b5-4564-97f4-7d17299d3ddd | 6e3f7528-650a-4d0f-956a-5babf2ef4fd6
C3 | 2 | VCCIN | ProPrj_pow-easyedapro:C0805 | 23087e86-c8b5-4564-97f4-7d17299d3ddd | 6e3f7528-650a-4d0f-956a-5babf2ef4fd6
C4 | 1 | VCCOUT | ProPrj_pow-easyedapro:C0805 | 72d2bf58-6353-4183-b7b6-6b4cb20d9fb2 | 905ff56c-14bb-4505-a252-f58795936c84
C4 | 2 | GND | ProPrj_pow-easyedapro:C0805 | 72d2bf58-6353-4183-b7b6-6b4cb20d9fb2 | 905ff56c-14bb-4505-a252-f58795936c84
C5 | 1 | VCCOUT | ProPrj_pow-easyedapro:C0805 | 2e962bbf-c5cf-4e30-9079-d0a39561dbfb | 8069594b-2fcd-4a02-875e-ec7e2216ed21
C5 | 2 | GND | ProPrj_pow-easyedapro:C0805 | 2e962bbf-c5cf-4e30-9079-d0a39561dbfb | 8069594b-2fcd-4a02-875e-ec7e2216ed21
C6 | 1 | Net-(C6-Pad1) | ProPrj_pow-easyedapro:C0603 | c6cc2986-c24c-49a6-9292-7f62d4b97e26 | 7a53606b-0dcc-4245-803b-9d87cdb2da9a
C6 | 2 | Net-(U5-SW) | ProPrj_pow-easyedapro:C0603 | c6cc2986-c24c-49a6-9292-7f62d4b97e26 | 7a53606b-0dcc-4245-803b-9d87cdb2da9a
C7 | 1 | VCCOUT | ProPrj_pow-easyedapro:C0603 | af627279-93d4-4241-adc3-1744a714d9f3 | 18a23152-5f7a-41a6-adf0-478e81632ba2
C7 | 2 | Net-(U5-FB) | ProPrj_pow-easyedapro:C0603 | af627279-93d4-4241-adc3-1744a714d9f3 | 18a23152-5f7a-41a6-adf0-478e81632ba2
C8 | 1 | GND | ProPrj_pow-easyedapro:C0805 | c504bdd2-2733-411f-bde3-000039744738 | a8b9b5ea-ff94-4f72-b218-bd10f378a5d2
C8 | 2 | VCCIN | ProPrj_pow-easyedapro:C0805 | c504bdd2-2733-411f-bde3-000039744738 | a8b9b5ea-ff94-4f72-b218-bd10f378a5d2
C9 | 1 | GND | ProPrj_pow-easyedapro:C0805 | 57b80bd0-39f0-4d18-b0c7-d87276b52727 | 56c0cbe0-7464-4605-8a6f-75b952cdbe9f
C9 | 2 | VCCIN | ProPrj_pow-easyedapro:C0805 | 57b80bd0-39f0-4d18-b0c7-d87276b52727 | 56c0cbe0-7464-4605-8a6f-75b952cdbe9f
C10 | 1 | GND | ProPrj_pow-easyedapro:C0805 | 11f0bf5d-6d31-4b30-b69c-010147395bed | d5407d85-29da-4f9a-a644-b58888c76032
C10 | 2 | VCCIN | ProPrj_pow-easyedapro:C0805 | 11f0bf5d-6d31-4b30-b69c-010147395bed | d5407d85-29da-4f9a-a644-b58888c76032
C11 | 1 | Net-(U5-VCC) | ProPrj_pow-easyedapro:C0603 | e0c9893c-b05d-4818-834e-09107e14feec | ce10c02c-668b-4ccb-bf71-26d9173ccedb
C11 | 2 | GND | ProPrj_pow-easyedapro:C0603 | e0c9893c-b05d-4818-834e-09107e14feec | ce10c02c-668b-4ccb-bf71-26d9173ccedb
C12 | 1 | VCCOUT1 | ProPrj_pow-easyedapro:C0805 | c2c508c0-bf8f-451f-9bde-c009541b1a25 | 7fa0ac60-c9b9-4979-bb88-59778011b39d
C12 | 2 | GND | ProPrj_pow-easyedapro:C0805 | c2c508c0-bf8f-451f-9bde-c009541b1a25 | 7fa0ac60-c9b9-4979-bb88-59778011b39d
C13 | 1 | VCCOUT1 | ProPrj_pow-easyedapro:C0805 | 38ec3d84-3969-4862-bada-fc1936cae331 | 8c9db3bb-3ed0-43ff-89ad-ef59067bf8f6
C13 | 2 | GND | ProPrj_pow-easyedapro:C0805 | 38ec3d84-3969-4862-bada-fc1936cae331 | 8c9db3bb-3ed0-43ff-89ad-ef59067bf8f6
C14 | 1 | Net-(C14-Pad1) | ProPrj_pow-easyedapro:C0603 | 6335cdf8-e346-4349-8c81-24dc77578d3b | 95fbb784-ed8e-4c73-bb4f-afae9b0ed530
C14 | 2 | Net-(U1-SW) | ProPrj_pow-easyedapro:C0603 | 6335cdf8-e346-4349-8c81-24dc77578d3b | 95fbb784-ed8e-4c73-bb4f-afae9b0ed530
C15 | 1 | VCCOUT1 | ProPrj_pow-easyedapro:C0603 | 4dd19102-da9a-46ca-8fb9-09c124bb3f9d | 8cd93dd1-539b-475e-842c-469d8067a6c0
C15 | 2 | Net-(U1-FB) | ProPrj_pow-easyedapro:C0603 | 4dd19102-da9a-46ca-8fb9-09c124bb3f9d | 8cd93dd1-539b-475e-842c-469d8067a6c0
C16 | 1 | Net-(U1-VCC) | ProPrj_pow-easyedapro:C0603 | 35d280a0-4851-40bf-8536-f3caf303f1d6 | 53be75bc-39a1-4790-aab4-5f783507bdbc
C16 | 2 | GND | ProPrj_pow-easyedapro:C0603 | 35d280a0-4851-40bf-8536-f3caf303f1d6 | 53be75bc-39a1-4790-aab4-5f783507bdbc
C58 | 1 | VCCIN | ProPrj_pow-easyedapro:C0805_C58 | 6b5f31ba-0130-4157-888a-45b77c490136 | 31bc1cc5-b329-416e-8ab7-29c62b43bb07
C58 | 2 | GND | ProPrj_pow-easyedapro:C0805_C58 | 6b5f31ba-0130-4157-888a-45b77c490136 | 31bc1cc5-b329-416e-8ab7-29c62b43bb07
C59 | 1 | VCCIN | ProPrj_pow-easyedapro:C0805_C59 | d4f09e2c-5d51-45a8-8b9e-09a698c97715 | fd91b041-8aaf-4d76-93a2-d3f963299ba0
C59 | 2 | GND | ProPrj_pow-easyedapro:C0805_C59 | d4f09e2c-5d51-45a8-8b9e-09a698c97715 | fd91b041-8aaf-4d76-93a2-d3f963299ba0
C60 | 1 | VCCIN | ProPrj_pow-easyedapro:C0805_C60 | d68a2f01-8047-40b0-bf61-a3bae9a1620b | d3cca279-9f16-46d5-9048-b7995ace7fb8
C60 | 2 | GND | ProPrj_pow-easyedapro:C0805_C60 | d68a2f01-8047-40b0-bf61-a3bae9a1620b | d3cca279-9f16-46d5-9048-b7995ace7fb8
C61 | 1 | VCCIN | ProPrj_pow-easyedapro:C0805_C61 | 40f9e80c-3f30-4c43-853c-718f6dd60f85 | 28d5e85e-c0c7-4509-8459-fc7ea5b01f40
C61 | 2 | GND | ProPrj_pow-easyedapro:C0805_C61 | 40f9e80c-3f30-4c43-853c-718f6dd60f85 | 28d5e85e-c0c7-4509-8459-fc7ea5b01f40
CN1 | 1 | GND | ProPrj_pow-easyedapro:CONN-TH_XT60PW-M | e4d0630e-82af-4a79-92ae-d8a64a0afee4 | 473ee340-aff0-40db-8769-92d0b3d4fe71
CN1 | 2 | VCCIN | ProPrj_pow-easyedapro:CONN-TH_XT60PW-M | e4d0630e-82af-4a79-92ae-d8a64a0afee4 | 473ee340-aff0-40db-8769-92d0b3d4fe71
CN1 | 3 | GND | ProPrj_pow-easyedapro:CONN-TH_XT60PW-M | e4d0630e-82af-4a79-92ae-d8a64a0afee4 | 473ee340-aff0-40db-8769-92d0b3d4fe71
CN1 | 4 | GND | ProPrj_pow-easyedapro:CONN-TH_XT60PW-M | e4d0630e-82af-4a79-92ae-d8a64a0afee4 | 473ee340-aff0-40db-8769-92d0b3d4fe71
D1 | 1 | /VM | ProPrj_pow-easyedapro:SOD-123_L2.7-W1.8-LS3.7-RD | 57dec5da-6c74-4818-bf3e-1db1f6b62e60 | 9306bd9a-301b-4e4a-bf87-a307ab5e097a
D1 | 2 | GND | ProPrj_pow-easyedapro:SOD-123_L2.7-W1.8-LS3.7-RD | 57dec5da-6c74-4818-bf3e-1db1f6b62e60 | 9306bd9a-301b-4e4a-bf87-a307ab5e097a
J1 | 1 | /LAIN1 | ProPrj_pow-easyedapro:CONN-TH_LAIL-PZ2.54-8P-L | 5112548e-285c-4489-8e9e-88c8e0732f34 | 1dc8323d-9bc4-4a8f-91b4-48b0fb295b21
J1 | 2 | /LAIN2 | ProPrj_pow-easyedapro:CONN-TH_LAIL-PZ2.54-8P-L | 5112548e-285c-4489-8e9e-88c8e0732f34 | 1dc8323d-9bc4-4a8f-91b4-48b0fb295b21
J1 | 3 | /LBIN1 | ProPrj_pow-easyedapro:CONN-TH_LAIL-PZ2.54-8P-L | 5112548e-285c-4489-8e9e-88c8e0732f34 | 1dc8323d-9bc4-4a8f-91b4-48b0fb295b21
J1 | 4 | /LBIN2 | ProPrj_pow-easyedapro:CONN-TH_LAIL-PZ2.54-8P-L | 5112548e-285c-4489-8e9e-88c8e0732f34 | 1dc8323d-9bc4-4a8f-91b4-48b0fb295b21
J1 | 5 | GND | ProPrj_pow-easyedapro:CONN-TH_LAIL-PZ2.54-8P-L | 5112548e-285c-4489-8e9e-88c8e0732f34 | 1dc8323d-9bc4-4a8f-91b4-48b0fb295b21
J1 | 6 | /3.3V | ProPrj_pow-easyedapro:CONN-TH_LAIL-PZ2.54-8P-L | 5112548e-285c-4489-8e9e-88c8e0732f34 | 1dc8323d-9bc4-4a8f-91b4-48b0fb295b21
J1 | 7 | /LF_ENA | ProPrj_pow-easyedapro:CONN-TH_LAIL-PZ2.54-8P-L | 5112548e-285c-4489-8e9e-88c8e0732f34 | 1dc8323d-9bc4-4a8f-91b4-48b0fb295b21
J1 | 8 | /LF_ENB | ProPrj_pow-easyedapro:CONN-TH_LAIL-PZ2.54-8P-L | 5112548e-285c-4489-8e9e-88c8e0732f34 | 1dc8323d-9bc4-4a8f-91b4-48b0fb295b21
J2 | 1 | /RF_ENB | ProPrj_pow-easyedapro:CONN-TH_LAIL-PZ2.54-8P-L | ef2d492a-48b1-4996-9c39-5091efacfc96 | ce9a3634-beb9-4711-8e14-d60eae1e27a1
J2 | 2 | /RF_ENA | ProPrj_pow-easyedapro:CONN-TH_LAIL-PZ2.54-8P-L | ef2d492a-48b1-4996-9c39-5091efacfc96 | ce9a3634-beb9-4711-8e14-d60eae1e27a1
J2 | 3 | /3.3V | ProPrj_pow-easyedapro:CONN-TH_LAIL-PZ2.54-8P-L | ef2d492a-48b1-4996-9c39-5091efacfc96 | ce9a3634-beb9-4711-8e14-d60eae1e27a1
J2 | 4 | GND | ProPrj_pow-easyedapro:CONN-TH_LAIL-PZ2.54-8P-L | ef2d492a-48b1-4996-9c39-5091efacfc96 | ce9a3634-beb9-4711-8e14-d60eae1e27a1
J2 | 5 | /RAIN1 | ProPrj_pow-easyedapro:CONN-TH_LAIL-PZ2.54-8P-L | ef2d492a-48b1-4996-9c39-5091efacfc96 | ce9a3634-beb9-4711-8e14-d60eae1e27a1
J2 | 6 | /RAIN2 | ProPrj_pow-easyedapro:CONN-TH_LAIL-PZ2.54-8P-L | ef2d492a-48b1-4996-9c39-5091efacfc96 | ce9a3634-beb9-4711-8e14-d60eae1e27a1
J2 | 7 | /RBIN1 | ProPrj_pow-easyedapro:CONN-TH_LAIL-PZ2.54-8P-L | ef2d492a-48b1-4996-9c39-5091efacfc96 | ce9a3634-beb9-4711-8e14-d60eae1e27a1
J2 | 8 | /RBIN2 | ProPrj_pow-easyedapro:CONN-TH_LAIL-PZ2.54-8P-L | ef2d492a-48b1-4996-9c39-5091efacfc96 | ce9a3634-beb9-4711-8e14-d60eae1e27a1
J3 | 1 | /LAOUT2 | ProPrj_pow-easyedapro:CONN-TH_6P-P2.50_BX-XH2.54-6PZZ | 8c04e8b2-f09a-451e-9582-67f7d7caf0cb | 113f1858-6b92-4114-9f73-80916323fcff
J3 | 2 | /3.3V | ProPrj_pow-easyedapro:CONN-TH_6P-P2.50_BX-XH2.54-6PZZ | 8c04e8b2-f09a-451e-9582-67f7d7caf0cb | 113f1858-6b92-4114-9f73-80916323fcff
J3 | 3 | /LF_ENA | ProPrj_pow-easyedapro:CONN-TH_6P-P2.50_BX-XH2.54-6PZZ | 8c04e8b2-f09a-451e-9582-67f7d7caf0cb | 113f1858-6b92-4114-9f73-80916323fcff
J3 | 4 | /LF_ENB | ProPrj_pow-easyedapro:CONN-TH_6P-P2.50_BX-XH2.54-6PZZ | 8c04e8b2-f09a-451e-9582-67f7d7caf0cb | 113f1858-6b92-4114-9f73-80916323fcff
J3 | 5 | GND | ProPrj_pow-easyedapro:CONN-TH_6P-P2.50_BX-XH2.54-6PZZ | 8c04e8b2-f09a-451e-9582-67f7d7caf0cb | 113f1858-6b92-4114-9f73-80916323fcff
J3 | 6 | /LAOUT1 | ProPrj_pow-easyedapro:CONN-TH_6P-P2.50_BX-XH2.54-6PZZ | 8c04e8b2-f09a-451e-9582-67f7d7caf0cb | 113f1858-6b92-4114-9f73-80916323fcff
J4 | 1 | /RAOUT2 | ProPrj_pow-easyedapro:CONN-TH_6P-P2.50_BX-XH2.54-6PZZ | 4ba2f72a-f3a5-4eed-b8ad-2a634c3534d3 | 3621a9c9-f322-4450-a96a-85727be919ab
J4 | 2 | /3.3V | ProPrj_pow-easyedapro:CONN-TH_6P-P2.50_BX-XH2.54-6PZZ | 4ba2f72a-f3a5-4eed-b8ad-2a634c3534d3 | 3621a9c9-f322-4450-a96a-85727be919ab
J4 | 3 | /RF_ENA | ProPrj_pow-easyedapro:CONN-TH_6P-P2.50_BX-XH2.54-6PZZ | 4ba2f72a-f3a5-4eed-b8ad-2a634c3534d3 | 3621a9c9-f322-4450-a96a-85727be919ab
J4 | 4 | /RF_ENB | ProPrj_pow-easyedapro:CONN-TH_6P-P2.50_BX-XH2.54-6PZZ | 4ba2f72a-f3a5-4eed-b8ad-2a634c3534d3 | 3621a9c9-f322-4450-a96a-85727be919ab
J4 | 5 | GND | ProPrj_pow-easyedapro:CONN-TH_6P-P2.50_BX-XH2.54-6PZZ | 4ba2f72a-f3a5-4eed-b8ad-2a634c3534d3 | 3621a9c9-f322-4450-a96a-85727be919ab
J4 | 6 | /RAOUT1 | ProPrj_pow-easyedapro:CONN-TH_6P-P2.50_BX-XH2.54-6PZZ | 4ba2f72a-f3a5-4eed-b8ad-2a634c3534d3 | 3621a9c9-f322-4450-a96a-85727be919ab
J5 | 1 | /LAOUT2 | ProPrj_pow-easyedapro:HDR-TH_LAIL-PM2.54-7P-L | 766a0616-875f-42d8-8773-a2e6d72213b3 | b54be2a6-8e2d-430e-8129-7cb8f266c155
J5 | 2 | /LAOUT1 | ProPrj_pow-easyedapro:HDR-TH_LAIL-PM2.54-7P-L | 766a0616-875f-42d8-8773-a2e6d72213b3 | b54be2a6-8e2d-430e-8129-7cb8f266c155
J5 | 3 | /LBIN1 | ProPrj_pow-easyedapro:HDR-TH_LAIL-PM2.54-7P-L | 766a0616-875f-42d8-8773-a2e6d72213b3 | b54be2a6-8e2d-430e-8129-7cb8f266c155
J5 | 4 | /LBIN2 | ProPrj_pow-easyedapro:HDR-TH_LAIL-PM2.54-7P-L | 766a0616-875f-42d8-8773-a2e6d72213b3 | b54be2a6-8e2d-430e-8129-7cb8f266c155
J5 | 5 | /3.3V | ProPrj_pow-easyedapro:HDR-TH_LAIL-PM2.54-7P-L | 766a0616-875f-42d8-8773-a2e6d72213b3 | b54be2a6-8e2d-430e-8129-7cb8f266c155
J5 | 6 | /VM | ProPrj_pow-easyedapro:HDR-TH_LAIL-PM2.54-7P-L | 766a0616-875f-42d8-8773-a2e6d72213b3 | b54be2a6-8e2d-430e-8129-7cb8f266c155
J5 | 7 | GND | ProPrj_pow-easyedapro:HDR-TH_LAIL-PM2.54-7P-L | 766a0616-875f-42d8-8773-a2e6d72213b3 | b54be2a6-8e2d-430e-8129-7cb8f266c155
J6 | 1 | unconnected-(J6-Pad1) | ProPrj_pow-easyedapro:HDR-TH_LAIL-PM2.54-7P-L | 08693e48-0fe5-46f3-9019-0a8054827d94 | 6e1de153-858d-4afd-9828-4fd4efb7d19e
J6 | 2 | unconnected-(J6-Pad2) | ProPrj_pow-easyedapro:HDR-TH_LAIL-PM2.54-7P-L | 08693e48-0fe5-46f3-9019-0a8054827d94 | 6e1de153-858d-4afd-9828-4fd4efb7d19e
J6 | 3 | /LAIN1 | ProPrj_pow-easyedapro:HDR-TH_LAIL-PM2.54-7P-L | 08693e48-0fe5-46f3-9019-0a8054827d94 | 6e1de153-858d-4afd-9828-4fd4efb7d19e
J6 | 4 | /LAIN2 | ProPrj_pow-easyedapro:HDR-TH_LAIL-PM2.54-7P-L | 08693e48-0fe5-46f3-9019-0a8054827d94 | 6e1de153-858d-4afd-9828-4fd4efb7d19e
J6 | 5 | /3.3V | ProPrj_pow-easyedapro:HDR-TH_LAIL-PM2.54-7P-L | 08693e48-0fe5-46f3-9019-0a8054827d94 | 6e1de153-858d-4afd-9828-4fd4efb7d19e
J6 | 6 | /VM | ProPrj_pow-easyedapro:HDR-TH_LAIL-PM2.54-7P-L | 08693e48-0fe5-46f3-9019-0a8054827d94 | 6e1de153-858d-4afd-9828-4fd4efb7d19e
J6 | 7 | GND | ProPrj_pow-easyedapro:HDR-TH_LAIL-PM2.54-7P-L | 08693e48-0fe5-46f3-9019-0a8054827d94 | 6e1de153-858d-4afd-9828-4fd4efb7d19e
J7 | 1 | /RAOUT2 | ProPrj_pow-easyedapro:HDR-TH_LAIL-PM2.54-7P-L | f208105a-ff9d-4c3b-8650-04d6ba2ac73d | 59235e31-bc9d-44ca-a839-3602d11bced8
J7 | 2 | /RAOUT1 | ProPrj_pow-easyedapro:HDR-TH_LAIL-PM2.54-7P-L | f208105a-ff9d-4c3b-8650-04d6ba2ac73d | 59235e31-bc9d-44ca-a839-3602d11bced8
J7 | 3 | /RBIN1 | ProPrj_pow-easyedapro:HDR-TH_LAIL-PM2.54-7P-L | f208105a-ff9d-4c3b-8650-04d6ba2ac73d | 59235e31-bc9d-44ca-a839-3602d11bced8
J7 | 4 | /RBIN2 | ProPrj_pow-easyedapro:HDR-TH_LAIL-PM2.54-7P-L | f208105a-ff9d-4c3b-8650-04d6ba2ac73d | 59235e31-bc9d-44ca-a839-3602d11bced8
J7 | 5 | /3.3V | ProPrj_pow-easyedapro:HDR-TH_LAIL-PM2.54-7P-L | f208105a-ff9d-4c3b-8650-04d6ba2ac73d | 59235e31-bc9d-44ca-a839-3602d11bced8
J7 | 6 | /VM | ProPrj_pow-easyedapro:HDR-TH_LAIL-PM2.54-7P-L | f208105a-ff9d-4c3b-8650-04d6ba2ac73d | 59235e31-bc9d-44ca-a839-3602d11bced8
J7 | 7 | GND | ProPrj_pow-easyedapro:HDR-TH_LAIL-PM2.54-7P-L | f208105a-ff9d-4c3b-8650-04d6ba2ac73d | 59235e31-bc9d-44ca-a839-3602d11bced8
J8 | 1 | unconnected-(J8-Pad1) | ProPrj_pow-easyedapro:HDR-TH_LAIL-PM2.54-7P-L | 93c33505-69c1-49ed-9501-fe01a7061a5c | 706cf072-125d-4beb-90d9-126528c7e897
J8 | 2 | unconnected-(J8-Pad2) | ProPrj_pow-easyedapro:HDR-TH_LAIL-PM2.54-7P-L | 93c33505-69c1-49ed-9501-fe01a7061a5c | 706cf072-125d-4beb-90d9-126528c7e897
J8 | 3 | /RAIN1 | ProPrj_pow-easyedapro:HDR-TH_LAIL-PM2.54-7P-L | 93c33505-69c1-49ed-9501-fe01a7061a5c | 706cf072-125d-4beb-90d9-126528c7e897
J8 | 4 | /RAIN2 | ProPrj_pow-easyedapro:HDR-TH_LAIL-PM2.54-7P-L | 93c33505-69c1-49ed-9501-fe01a7061a5c | 706cf072-125d-4beb-90d9-126528c7e897
J8 | 5 | /3.3V | ProPrj_pow-easyedapro:HDR-TH_LAIL-PM2.54-7P-L | 93c33505-69c1-49ed-9501-fe01a7061a5c | 706cf072-125d-4beb-90d9-126528c7e897
J8 | 6 | /VM | ProPrj_pow-easyedapro:HDR-TH_LAIL-PM2.54-7P-L | 93c33505-69c1-49ed-9501-fe01a7061a5c | 706cf072-125d-4beb-90d9-126528c7e897
J8 | 7 | GND | ProPrj_pow-easyedapro:HDR-TH_LAIL-PM2.54-7P-L | 93c33505-69c1-49ed-9501-fe01a7061a5c | 706cf072-125d-4beb-90d9-126528c7e897
L1 | 1 | VCCOUT | ProPrj_pow-easyedapro:IND-SMD_L7.3-W6.6 | 5c5e4349-2926-40cb-b7ab-c67266cd6f10 | 6c59555d-478f-4c1f-9453-73f19cd84801
L1 | 2 | Net-(U5-SW) | ProPrj_pow-easyedapro:IND-SMD_L7.3-W6.6 | 5c5e4349-2926-40cb-b7ab-c67266cd6f10 | 6c59555d-478f-4c1f-9453-73f19cd84801
L2 | 1 | VCCOUT1 | ProPrj_pow-easyedapro:IND-SMD_L7.3-W6.6 | d97f0fd9-a549-49b7-b88f-26f1f5de5849 | d0740779-c4c8-4459-85ee-ec65c818e9b7
L2 | 2 | Net-(U1-SW) | ProPrj_pow-easyedapro:IND-SMD_L7.3-W6.6 | d97f0fd9-a549-49b7-b88f-26f1f5de5849 | d0740779-c4c8-4459-85ee-ec65c818e9b7
LED1 | 1 | Net-(LED1-C) | ProPrj_pow-easyedapro:LED_0603 | f419531e-10cf-498c-a31b-054a72ff144f | f788e50a-85fe-4344-b441-933eff04f471
LED1 | 2 | /VM | ProPrj_pow-easyedapro:LED_0603 | f419531e-10cf-498c-a31b-054a72ff144f | f788e50a-85fe-4344-b441-933eff04f471
R1 | 1 | Net-(C6-Pad1) | ProPrj_pow-easyedapro:R0603 | 61ba72f0-1ff7-421e-bab6-32709c92e1f4 | 6f82eca5-70b5-4264-97b1-8ea5a465e22b
R1 | 2 | Net-(U5-BST) | ProPrj_pow-easyedapro:R0603 | 61ba72f0-1ff7-421e-bab6-32709c92e1f4 | 6f82eca5-70b5-4264-97b1-8ea5a465e22b
R2 | 1 | VCCOUT | ProPrj_pow-easyedapro:R0603 | 2f26aac6-589c-4fdb-8d1f-1511160b43ea | 5841ff03-057a-4276-9f0e-5d3695529eb0
R2 | 2 | Net-(U5-FB) | ProPrj_pow-easyedapro:R0603 | 2f26aac6-589c-4fdb-8d1f-1511160b43ea | 5841ff03-057a-4276-9f0e-5d3695529eb0
R3 | 1 | Net-(U5-FB) | ProPrj_pow-easyedapro:R0603 | 9cb05ea4-0e7e-45f9-a0c6-c8a85922a2e1 | edf23295-c6f4-4445-be1a-51454ec126cc
R3 | 2 | GND | ProPrj_pow-easyedapro:R0603 | 9cb05ea4-0e7e-45f9-a0c6-c8a85922a2e1 | edf23295-c6f4-4445-be1a-51454ec126cc
R4 | 1 | Net-(USB1-CC1) | ProPrj_pow-easyedapro:R0603_R4 | 51d822eb-f890-4954-8e72-ba256bf78d42 | 7503f82f-a692-4485-a09a-09df8f520838
R4 | 2 | VCCOUT | ProPrj_pow-easyedapro:R0603_R4 | 51d822eb-f890-4954-8e72-ba256bf78d42 | 7503f82f-a692-4485-a09a-09df8f520838
R5 | 1 | VCCOUT | ProPrj_pow-easyedapro:R0603_R5 | 78040820-ff9e-42d7-b0d1-b3506ef38a79 | 79e6f318-2b62-4e4a-af60-7811a36600c4
R5 | 2 | Net-(USB1-CC2) | ProPrj_pow-easyedapro:R0603_R5 | 78040820-ff9e-42d7-b0d1-b3506ef38a79 | 79e6f318-2b62-4e4a-af60-7811a36600c4
R6 | 1 | Net-(C14-Pad1) | ProPrj_pow-easyedapro:R0603 | ce3b80d9-e6c0-49d5-b3cb-af47cac27dfd | 3970d737-4f71-4414-a59a-cbcc951723fa
R6 | 2 | Net-(U1-BST) | ProPrj_pow-easyedapro:R0603 | ce3b80d9-e6c0-49d5-b3cb-af47cac27dfd | 3970d737-4f71-4414-a59a-cbcc951723fa
R7 | 1 | Net-(U5-EN) | ProPrj_pow-easyedapro:R0603 | efe14a0c-8a71-47ab-85be-733947c107ef | 0ef5e38e-42c1-408b-ae23-517a6d893bb9
R7 | 2 | VCCIN | ProPrj_pow-easyedapro:R0603 | efe14a0c-8a71-47ab-85be-733947c107ef | 0ef5e38e-42c1-408b-ae23-517a6d893bb9
R8 | 1 | Net-(USB2-CC1) | ProPrj_pow-easyedapro:R0603_R8 | cdd45272-2df1-4a11-9e0f-a6db088dc14b | 99df8970-c0f5-49a8-8580-96bb6294665f
R8 | 2 | VCCOUT1 | ProPrj_pow-easyedapro:R0603_R8 | cdd45272-2df1-4a11-9e0f-a6db088dc14b | 99df8970-c0f5-49a8-8580-96bb6294665f
R9 | 1 | VCCOUT1 | ProPrj_pow-easyedapro:R0603_R9 | af9c484d-8540-47b2-971c-ffdd4f47e8a1 | 2568b238-d9db-45ea-8900-cebd7e0a3cf3
R9 | 2 | Net-(USB2-CC2) | ProPrj_pow-easyedapro:R0603_R9 | af9c484d-8540-47b2-971c-ffdd4f47e8a1 | 2568b238-d9db-45ea-8900-cebd7e0a3cf3
R10 | 1 | GND | ProPrj_pow-easyedapro:R0603 | 2b2a0e58-b563-4535-ad58-7efa42b84bdc | d2b0a5c7-90d1-4ce6-9b6a-85680d5d1d9d
R10 | 2 | Net-(U5-EN) | ProPrj_pow-easyedapro:R0603 | 2b2a0e58-b563-4535-ad58-7efa42b84bdc | d2b0a5c7-90d1-4ce6-9b6a-85680d5d1d9d
R11 | 1 | VCCOUT1 | ProPrj_pow-easyedapro:R0603 | 886d6720-7b69-4064-87df-b892b91ca5f9 | 075139c1-6232-4985-ae3d-e34fd60cfb9c
R11 | 2 | Net-(U1-FB) | ProPrj_pow-easyedapro:R0603 | 886d6720-7b69-4064-87df-b892b91ca5f9 | 075139c1-6232-4985-ae3d-e34fd60cfb9c
R12 | 1 | Net-(U1-FB) | ProPrj_pow-easyedapro:R0603 | b306b020-325f-4f20-add0-3304ba71f81b | 2534c34c-3e7f-466b-8445-7f2018436395
R12 | 2 | GND | ProPrj_pow-easyedapro:R0603 | b306b020-325f-4f20-add0-3304ba71f81b | 2534c34c-3e7f-466b-8445-7f2018436395
R13 | 1 | Net-(U1-EN) | ProPrj_pow-easyedapro:R0603 | de05160c-f8f1-46ab-a932-784272a100a8 | 22e7aa17-d0e4-4215-931f-9e296f9f94d2
R13 | 2 | VCCIN | ProPrj_pow-easyedapro:R0603 | de05160c-f8f1-46ab-a932-784272a100a8 | 22e7aa17-d0e4-4215-931f-9e296f9f94d2
R14 | 1 | GND | ProPrj_pow-easyedapro:R0603 | 71f19bc7-a25f-4903-8983-fc5cf7c55e25 | ec281cc4-a389-401f-8791-28d185e6c9e0
R14 | 2 | Net-(U1-EN) | ProPrj_pow-easyedapro:R0603 | 71f19bc7-a25f-4903-8983-fc5cf7c55e25 | ec281cc4-a389-401f-8791-28d185e6c9e0
R15 | 1 | GND | ProPrj_pow-easyedapro:R0603_R15 | 5858d3cd-12b7-4cdd-bd08-edd0d1bce6c1 | a34e44de-35d5-4dfe-ae66-dc3f779164c8
R15 | 2 | Net-(LED1-C) | ProPrj_pow-easyedapro:R0603_R15 | 5858d3cd-12b7-4cdd-bd08-edd0d1bce6c1 | a34e44de-35d5-4dfe-ae66-dc3f779164c8
SW2 | 1 | /VM | ProPrj_pow-easyedapro:SW-TH_SS-12D10L5 | 7395b7dc-db82-4265-8a70-dee9f300b3c4 | f1f5035e-89b4-4605-b11c-ce960b77a46e
SW2 | 2 | VCCIN | ProPrj_pow-easyedapro:SW-TH_SS-12D10L5 | 7395b7dc-db82-4265-8a70-dee9f300b3c4 | f1f5035e-89b4-4605-b11c-ce960b77a46e
SW2 | 3 | unconnected-(SW2-Pad3) | ProPrj_pow-easyedapro:SW-TH_SS-12D10L5 | 7395b7dc-db82-4265-8a70-dee9f300b3c4 | f1f5035e-89b4-4605-b11c-ce960b77a46e
U1 | 1 | GND | ProPrj_pow-easyedapro:TSOT-23-8_L2.9-W1.6-P0.65-LS2.8-BL | 67683d25-7046-4451-ae87-ffdebe9a5c02 | 4c72bf91-89f8-4041-b979-acac13b25d02
U1 | 2 | VCCIN | ProPrj_pow-easyedapro:TSOT-23-8_L2.9-W1.6-P0.65-LS2.8-BL | 67683d25-7046-4451-ae87-ffdebe9a5c02 | 4c72bf91-89f8-4041-b979-acac13b25d02
U1 | 3 | Net-(U1-SW) | ProPrj_pow-easyedapro:TSOT-23-8_L2.9-W1.6-P0.65-LS2.8-BL | 67683d25-7046-4451-ae87-ffdebe9a5c02 | 4c72bf91-89f8-4041-b979-acac13b25d02
U1 | 4 | GND | ProPrj_pow-easyedapro:TSOT-23-8_L2.9-W1.6-P0.65-LS2.8-BL | 67683d25-7046-4451-ae87-ffdebe9a5c02 | 4c72bf91-89f8-4041-b979-acac13b25d02
U1 | 5 | Net-(U1-BST) | ProPrj_pow-easyedapro:TSOT-23-8_L2.9-W1.6-P0.65-LS2.8-BL | 67683d25-7046-4451-ae87-ffdebe9a5c02 | 4c72bf91-89f8-4041-b979-acac13b25d02
U1 | 6 | Net-(U1-EN) | ProPrj_pow-easyedapro:TSOT-23-8_L2.9-W1.6-P0.65-LS2.8-BL | 67683d25-7046-4451-ae87-ffdebe9a5c02 | 4c72bf91-89f8-4041-b979-acac13b25d02
U1 | 7 | Net-(U1-VCC) | ProPrj_pow-easyedapro:TSOT-23-8_L2.9-W1.6-P0.65-LS2.8-BL | 67683d25-7046-4451-ae87-ffdebe9a5c02 | 4c72bf91-89f8-4041-b979-acac13b25d02
U1 | 8 | Net-(U1-FB) | ProPrj_pow-easyedapro:TSOT-23-8_L2.9-W1.6-P0.65-LS2.8-BL | 67683d25-7046-4451-ae87-ffdebe9a5c02 | 4c72bf91-89f8-4041-b979-acac13b25d02
U5 | 1 | GND | ProPrj_pow-easyedapro:TSOT-23-8_L2.9-W1.6-P0.65-LS2.8-BL | d3a73723-1e55-4c12-8185-20c99c1305b4 | 03e3ab6a-440a-43d8-afa5-23b546309bee
U5 | 2 | VCCIN | ProPrj_pow-easyedapro:TSOT-23-8_L2.9-W1.6-P0.65-LS2.8-BL | d3a73723-1e55-4c12-8185-20c99c1305b4 | 03e3ab6a-440a-43d8-afa5-23b546309bee
U5 | 3 | Net-(U5-SW) | ProPrj_pow-easyedapro:TSOT-23-8_L2.9-W1.6-P0.65-LS2.8-BL | d3a73723-1e55-4c12-8185-20c99c1305b4 | 03e3ab6a-440a-43d8-afa5-23b546309bee
U5 | 4 | GND | ProPrj_pow-easyedapro:TSOT-23-8_L2.9-W1.6-P0.65-LS2.8-BL | d3a73723-1e55-4c12-8185-20c99c1305b4 | 03e3ab6a-440a-43d8-afa5-23b546309bee
U5 | 5 | Net-(U5-BST) | ProPrj_pow-easyedapro:TSOT-23-8_L2.9-W1.6-P0.65-LS2.8-BL | d3a73723-1e55-4c12-8185-20c99c1305b4 | 03e3ab6a-440a-43d8-afa5-23b546309bee
U5 | 6 | Net-(U5-EN) | ProPrj_pow-easyedapro:TSOT-23-8_L2.9-W1.6-P0.65-LS2.8-BL | d3a73723-1e55-4c12-8185-20c99c1305b4 | 03e3ab6a-440a-43d8-afa5-23b546309bee
U5 | 7 | Net-(U5-VCC) | ProPrj_pow-easyedapro:TSOT-23-8_L2.9-W1.6-P0.65-LS2.8-BL | d3a73723-1e55-4c12-8185-20c99c1305b4 | 03e3ab6a-440a-43d8-afa5-23b546309bee
U5 | 8 | Net-(U5-FB) | ProPrj_pow-easyedapro:TSOT-23-8_L2.9-W1.6-P0.65-LS2.8-BL | d3a73723-1e55-4c12-8185-20c99c1305b4 | 03e3ab6a-440a-43d8-afa5-23b546309bee
USB1 | 13 | GND | ProPrj_pow-easyedapro:TYPE-C-SMD_LAIL-TYPE-C-16PIN-08-WT | 1b301c4a-3f38-4d16-9c3d-389362e3cffb | 5d977d5f-25f2-412d-b08f-976409cfa901
USB1 | 14 | GND | ProPrj_pow-easyedapro:TYPE-C-SMD_LAIL-TYPE-C-16PIN-08-WT | 1b301c4a-3f38-4d16-9c3d-389362e3cffb | 5d977d5f-25f2-412d-b08f-976409cfa901
USB1 | 15 | GND | ProPrj_pow-easyedapro:TYPE-C-SMD_LAIL-TYPE-C-16PIN-08-WT | 1b301c4a-3f38-4d16-9c3d-389362e3cffb | 5d977d5f-25f2-412d-b08f-976409cfa901
USB1 | 16 | GND | ProPrj_pow-easyedapro:TYPE-C-SMD_LAIL-TYPE-C-16PIN-08-WT | 1b301c4a-3f38-4d16-9c3d-389362e3cffb | 5d977d5f-25f2-412d-b08f-976409cfa901
USB1 | A1B12 | GND | ProPrj_pow-easyedapro:TYPE-C-SMD_LAIL-TYPE-C-16PIN-08-WT | 1b301c4a-3f38-4d16-9c3d-389362e3cffb | 5d977d5f-25f2-412d-b08f-976409cfa901
USB1 | A4B9 | VCCOUT | ProPrj_pow-easyedapro:TYPE-C-SMD_LAIL-TYPE-C-16PIN-08-WT | 1b301c4a-3f38-4d16-9c3d-389362e3cffb | 5d977d5f-25f2-412d-b08f-976409cfa901
USB1 | A5 | Net-(USB1-CC1) | ProPrj_pow-easyedapro:TYPE-C-SMD_LAIL-TYPE-C-16PIN-08-WT | 1b301c4a-3f38-4d16-9c3d-389362e3cffb | 5d977d5f-25f2-412d-b08f-976409cfa901
USB1 | A6 | unconnected-(USB1-DP1-PadA6) | ProPrj_pow-easyedapro:TYPE-C-SMD_LAIL-TYPE-C-16PIN-08-WT | 1b301c4a-3f38-4d16-9c3d-389362e3cffb | 5d977d5f-25f2-412d-b08f-976409cfa901
USB1 | A7 | unconnected-(USB1-DN1-PadA7) | ProPrj_pow-easyedapro:TYPE-C-SMD_LAIL-TYPE-C-16PIN-08-WT | 1b301c4a-3f38-4d16-9c3d-389362e3cffb | 5d977d5f-25f2-412d-b08f-976409cfa901
USB1 | A8 | unconnected-(USB1-SBU1-PadA8) | ProPrj_pow-easyedapro:TYPE-C-SMD_LAIL-TYPE-C-16PIN-08-WT | 1b301c4a-3f38-4d16-9c3d-389362e3cffb | 5d977d5f-25f2-412d-b08f-976409cfa901
USB1 | B1A12 | GND | ProPrj_pow-easyedapro:TYPE-C-SMD_LAIL-TYPE-C-16PIN-08-WT | 1b301c4a-3f38-4d16-9c3d-389362e3cffb | 5d977d5f-25f2-412d-b08f-976409cfa901
USB1 | B4A9 | VCCOUT | ProPrj_pow-easyedapro:TYPE-C-SMD_LAIL-TYPE-C-16PIN-08-WT | 1b301c4a-3f38-4d16-9c3d-389362e3cffb | 5d977d5f-25f2-412d-b08f-976409cfa901
USB1 | B5 | Net-(USB1-CC2) | ProPrj_pow-easyedapro:TYPE-C-SMD_LAIL-TYPE-C-16PIN-08-WT | 1b301c4a-3f38-4d16-9c3d-389362e3cffb | 5d977d5f-25f2-412d-b08f-976409cfa901
USB1 | B6 | unconnected-(USB1-DP2-PadB6) | ProPrj_pow-easyedapro:TYPE-C-SMD_LAIL-TYPE-C-16PIN-08-WT | 1b301c4a-3f38-4d16-9c3d-389362e3cffb | 5d977d5f-25f2-412d-b08f-976409cfa901
USB1 | B7 | unconnected-(USB1-DN2-PadB7) | ProPrj_pow-easyedapro:TYPE-C-SMD_LAIL-TYPE-C-16PIN-08-WT | 1b301c4a-3f38-4d16-9c3d-389362e3cffb | 5d977d5f-25f2-412d-b08f-976409cfa901
USB1 | B8 | unconnected-(USB1-SBU2-PadB8) | ProPrj_pow-easyedapro:TYPE-C-SMD_LAIL-TYPE-C-16PIN-08-WT | 1b301c4a-3f38-4d16-9c3d-389362e3cffb | 5d977d5f-25f2-412d-b08f-976409cfa901
USB2 | 13 | GND | ProPrj_pow-easyedapro:TYPE-C-SMD_LAIL-TYPE-C-16PIN-08-WT | b0689d2e-5e7e-4a3a-99e5-4a5d671d9054 | 69c736fa-ef6e-42bc-b7ca-a8d7cea245e4
USB2 | 14 | GND | ProPrj_pow-easyedapro:TYPE-C-SMD_LAIL-TYPE-C-16PIN-08-WT | b0689d2e-5e7e-4a3a-99e5-4a5d671d9054 | 69c736fa-ef6e-42bc-b7ca-a8d7cea245e4
USB2 | 15 | GND | ProPrj_pow-easyedapro:TYPE-C-SMD_LAIL-TYPE-C-16PIN-08-WT | b0689d2e-5e7e-4a3a-99e5-4a5d671d9054 | 69c736fa-ef6e-42bc-b7ca-a8d7cea245e4
USB2 | 16 | GND | ProPrj_pow-easyedapro:TYPE-C-SMD_LAIL-TYPE-C-16PIN-08-WT | b0689d2e-5e7e-4a3a-99e5-4a5d671d9054 | 69c736fa-ef6e-42bc-b7ca-a8d7cea245e4
USB2 | A1B12 | GND | ProPrj_pow-easyedapro:TYPE-C-SMD_LAIL-TYPE-C-16PIN-08-WT | b0689d2e-5e7e-4a3a-99e5-4a5d671d9054 | 69c736fa-ef6e-42bc-b7ca-a8d7cea245e4
USB2 | A4B9 | VCCOUT1 | ProPrj_pow-easyedapro:TYPE-C-SMD_LAIL-TYPE-C-16PIN-08-WT | b0689d2e-5e7e-4a3a-99e5-4a5d671d9054 | 69c736fa-ef6e-42bc-b7ca-a8d7cea245e4
USB2 | A5 | Net-(USB2-CC1) | ProPrj_pow-easyedapro:TYPE-C-SMD_LAIL-TYPE-C-16PIN-08-WT | b0689d2e-5e7e-4a3a-99e5-4a5d671d9054 | 69c736fa-ef6e-42bc-b7ca-a8d7cea245e4
USB2 | A6 | unconnected-(USB2-DP1-PadA6) | ProPrj_pow-easyedapro:TYPE-C-SMD_LAIL-TYPE-C-16PIN-08-WT | b0689d2e-5e7e-4a3a-99e5-4a5d671d9054 | 69c736fa-ef6e-42bc-b7ca-a8d7cea245e4
USB2 | A7 | unconnected-(USB2-DN1-PadA7) | ProPrj_pow-easyedapro:TYPE-C-SMD_LAIL-TYPE-C-16PIN-08-WT | b0689d2e-5e7e-4a3a-99e5-4a5d671d9054 | 69c736fa-ef6e-42bc-b7ca-a8d7cea245e4
USB2 | A8 | unconnected-(USB2-SBU1-PadA8) | ProPrj_pow-easyedapro:TYPE-C-SMD_LAIL-TYPE-C-16PIN-08-WT | b0689d2e-5e7e-4a3a-99e5-4a5d671d9054 | 69c736fa-ef6e-42bc-b7ca-a8d7cea245e4
USB2 | B1A12 | GND | ProPrj_pow-easyedapro:TYPE-C-SMD_LAIL-TYPE-C-16PIN-08-WT | b0689d2e-5e7e-4a3a-99e5-4a5d671d9054 | 69c736fa-ef6e-42bc-b7ca-a8d7cea245e4
USB2 | B4A9 | VCCOUT1 | ProPrj_pow-easyedapro:TYPE-C-SMD_LAIL-TYPE-C-16PIN-08-WT | b0689d2e-5e7e-4a3a-99e5-4a5d671d9054 | 69c736fa-ef6e-42bc-b7ca-a8d7cea245e4
USB2 | B5 | Net-(USB2-CC2) | ProPrj_pow-easyedapro:TYPE-C-SMD_LAIL-TYPE-C-16PIN-08-WT | b0689d2e-5e7e-4a3a-99e5-4a5d671d9054 | 69c736fa-ef6e-42bc-b7ca-a8d7cea245e4
USB2 | B6 | unconnected-(USB2-DP2-PadB6) | ProPrj_pow-easyedapro:TYPE-C-SMD_LAIL-TYPE-C-16PIN-08-WT | b0689d2e-5e7e-4a3a-99e5-4a5d671d9054 | 69c736fa-ef6e-42bc-b7ca-a8d7cea245e4
USB2 | B7 | unconnected-(USB2-DN2-PadB7) | ProPrj_pow-easyedapro:TYPE-C-SMD_LAIL-TYPE-C-16PIN-08-WT | b0689d2e-5e7e-4a3a-99e5-4a5d671d9054 | 69c736fa-ef6e-42bc-b7ca-a8d7cea245e4
USB2 | B8 | unconnected-(USB2-SBU2-PadB8) | ProPrj_pow-easyedapro:TYPE-C-SMD_LAIL-TYPE-C-16PIN-08-WT | b0689d2e-5e7e-4a3a-99e5-4a5d671d9054 | 69c736fa-ef6e-42bc-b7ca-a8d7cea245e4

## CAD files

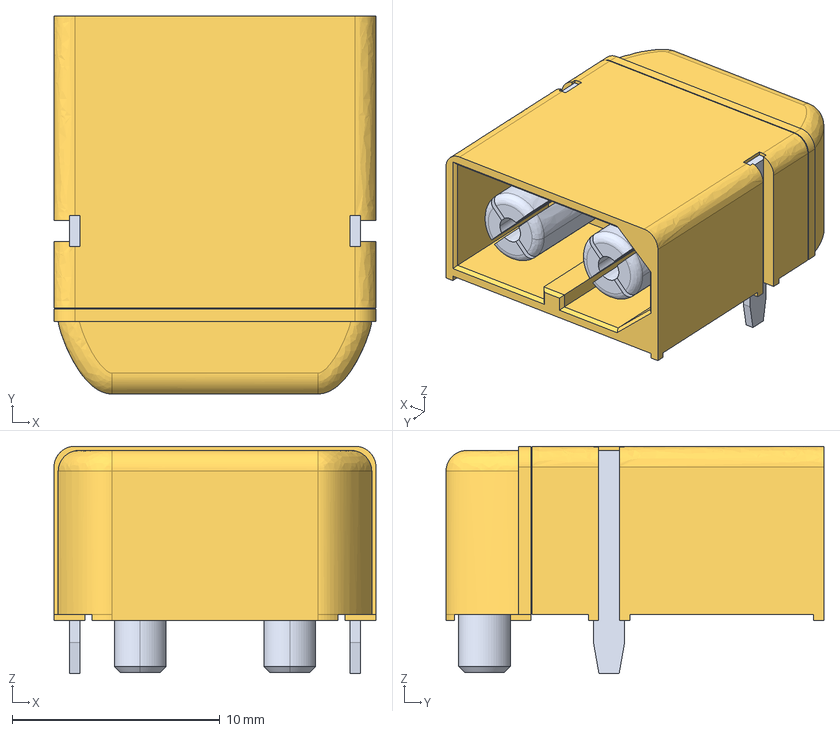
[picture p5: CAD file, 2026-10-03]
pcb/power/kicad/3dmodels/AMASS_XT60PW-M_1x02_P7.20mm_Horizontal.step
15.5 x 18.2 x 10.9 mm

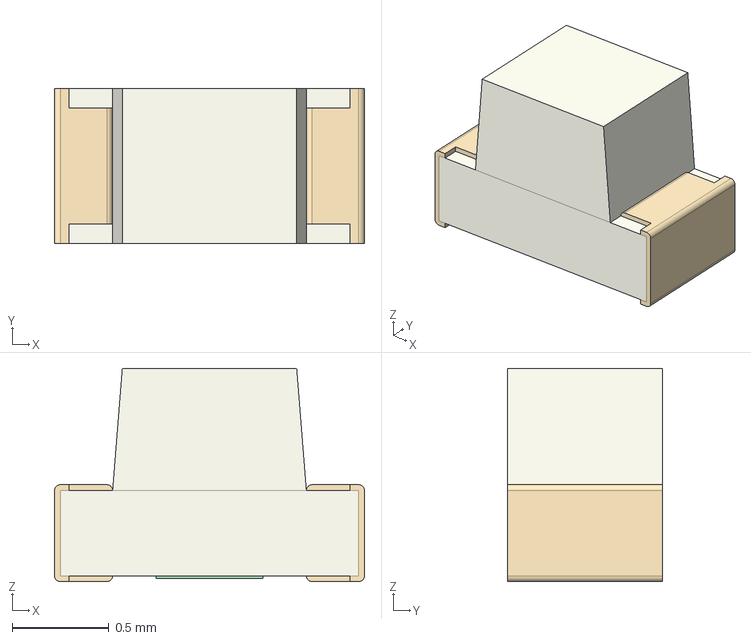
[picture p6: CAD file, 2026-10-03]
pcb/power/kicad/3dmodels/LED_0603_1608Metric.step
1.60 x 0.8 x 1.10 mm

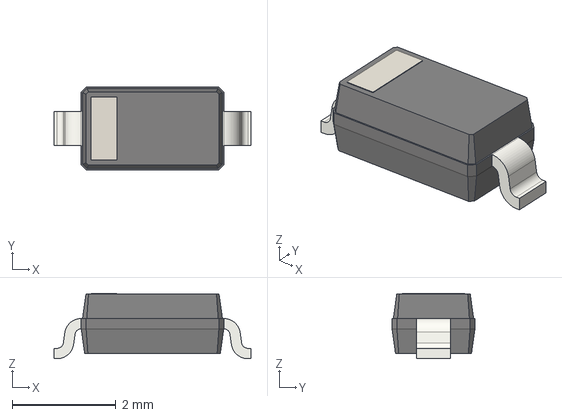
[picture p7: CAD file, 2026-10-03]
pcb/power/kicad/3dmodels/D_SOD-123.step
3.80 x 1.60 x 1.26 mm

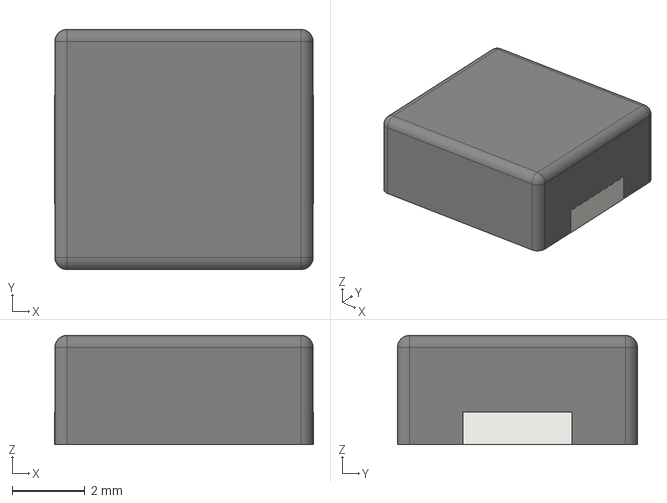
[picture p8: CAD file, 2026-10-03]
pcb/power/kicad/3dmodels/L_TechFuse_SL0630.step
7.12 x 6.60 x 3.00 mm

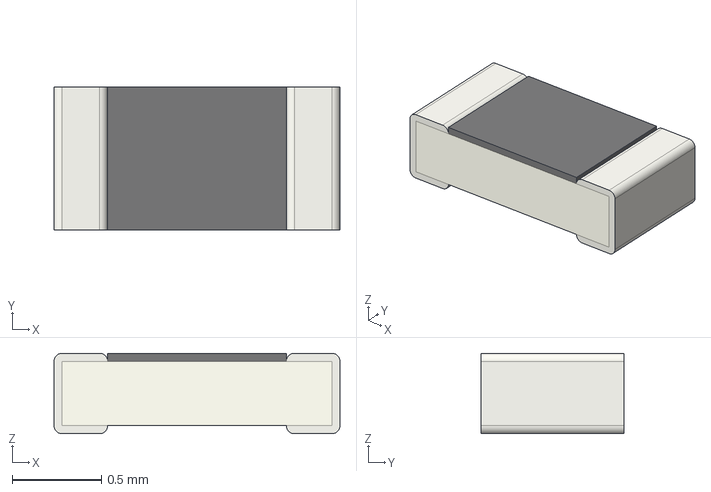
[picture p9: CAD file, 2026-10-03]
pcb/power/kicad/3dmodels/R_0603_1608Metric.step
1.60 x 0.8 x 0.45 mm

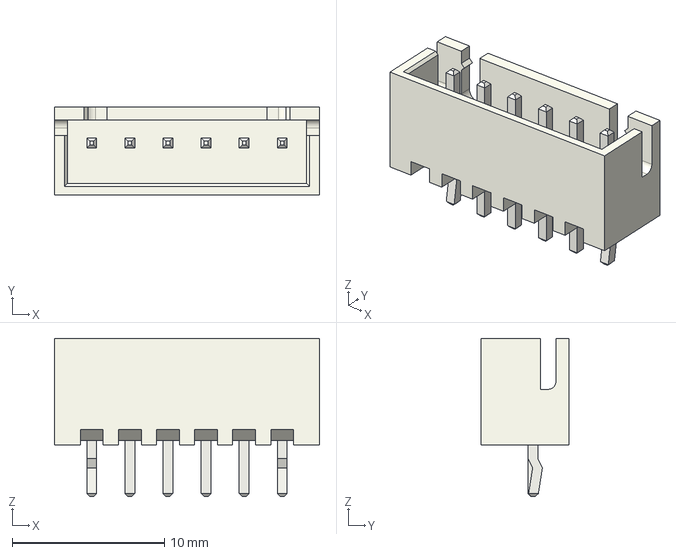
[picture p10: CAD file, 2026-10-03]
pcb/power/kicad/3dmodels/JST_XH_B6B-XH-A_1x06_P2.50mm_Vertical.step
17.4 x 5.75 x 10.4 mm

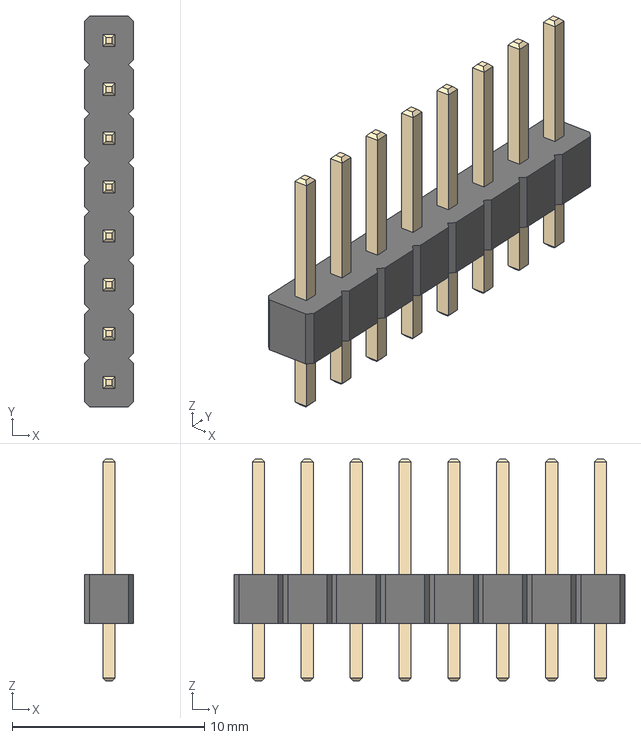
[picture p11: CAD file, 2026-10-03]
pcb/power/kicad/3dmodels/PinHeader_1x08_P2.54mm_Vertical.step
2.54 x 20.3 x 11.5 mm

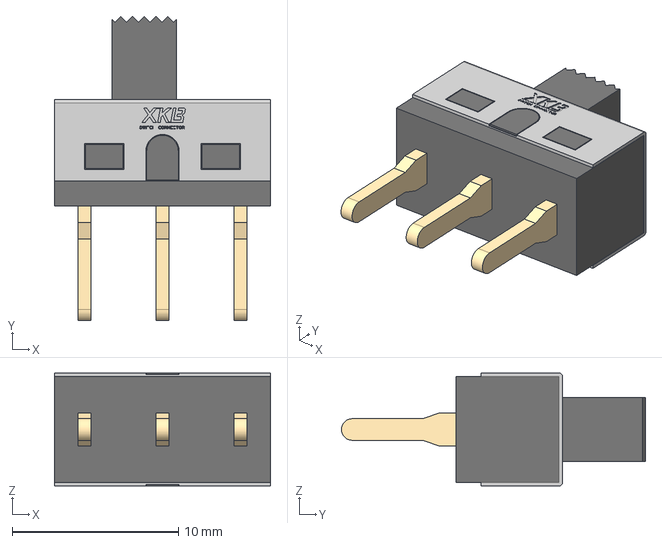
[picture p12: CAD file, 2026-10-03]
pcb/power/kicad/3dmodels/SS-12D10L5.step
13.0 x 18.3 x 6.80 mm

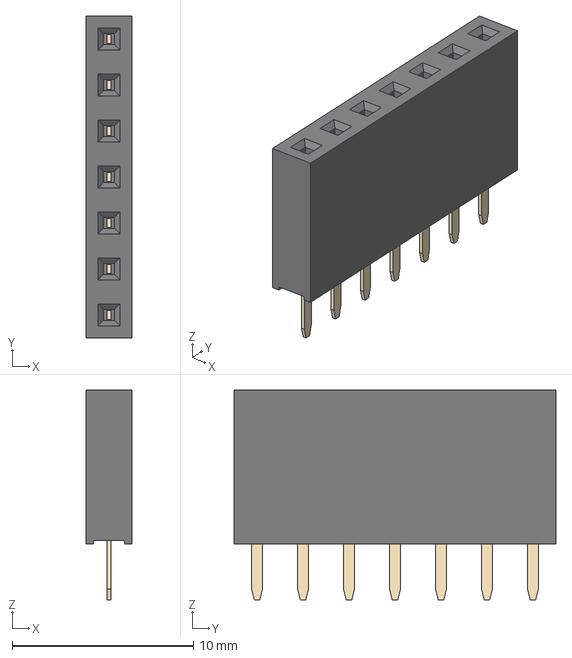
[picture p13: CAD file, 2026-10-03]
pcb/power/kicad/3dmodels/PinSocket_1x07_P2.54mm_Vertical.step
2.54 x 17.8 x 11.6 mm

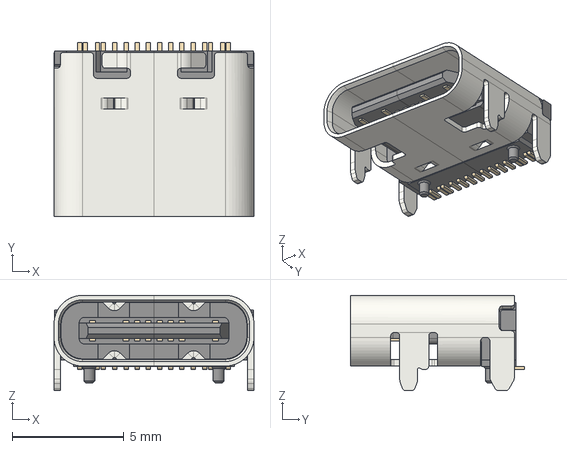
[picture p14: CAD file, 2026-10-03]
pcb/power/kicad/3dmodels/USB_C_Receptacle_GCT_USB4105-xx-A_16P_TopMnt_Horizontal.step
8.94 x 7.78 x 4.26 mm

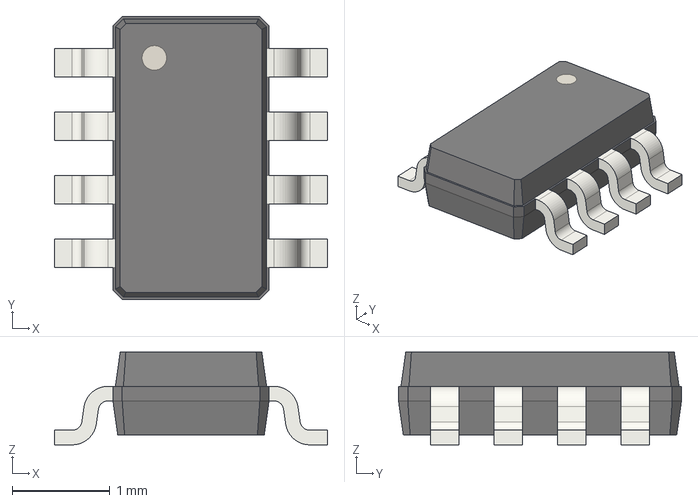
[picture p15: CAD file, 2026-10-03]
pcb/power/kicad/3dmodels/TSOT-23-8.step
2.80 x 2.90 x 0.95 mm

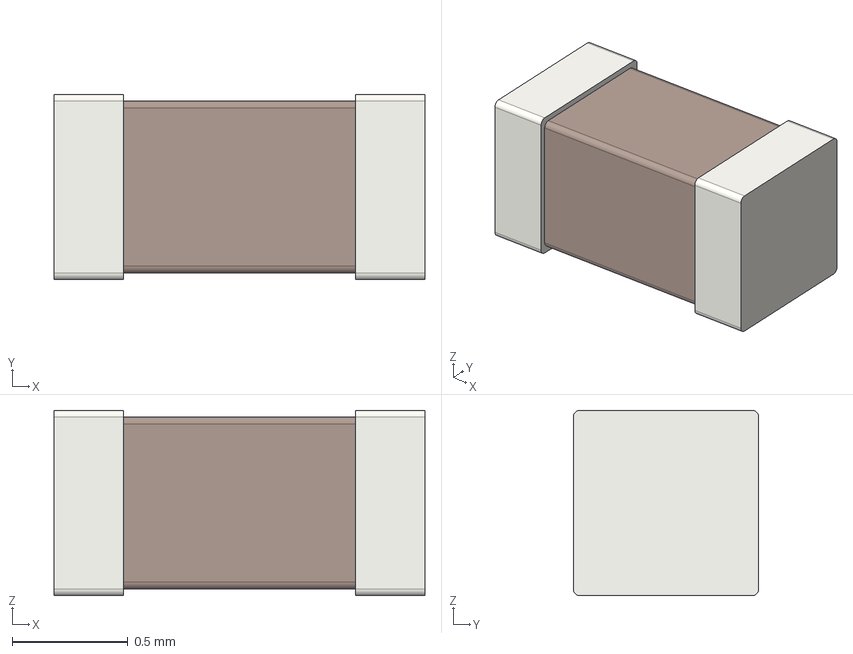
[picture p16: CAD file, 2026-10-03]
pcb/power/kicad/3dmodels/C_0603_1608Metric.step
1.60 x 0.8 x 0.8 mm

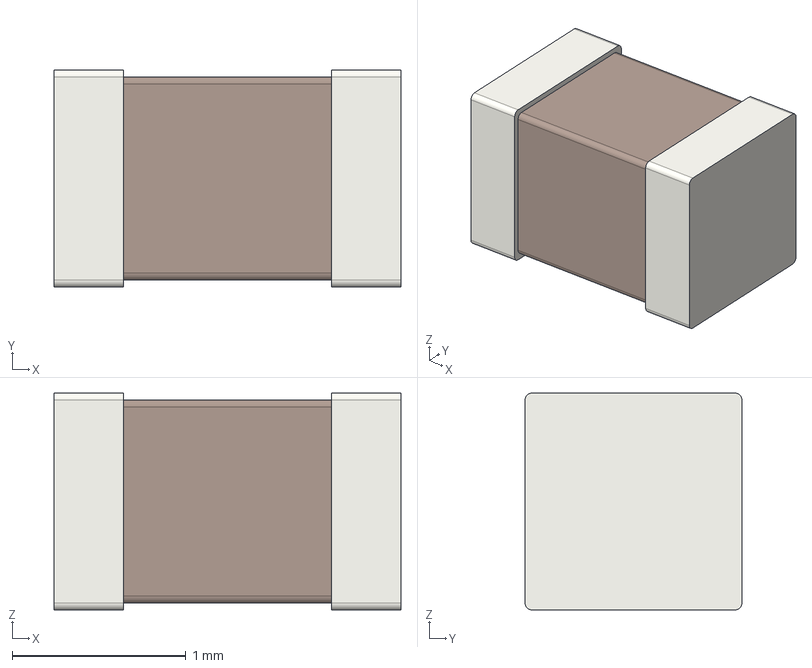
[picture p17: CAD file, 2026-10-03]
pcb/power/kicad/3dmodels/C_0805_2012Metric.step
2.00 x 1.25 x 1.25 mm

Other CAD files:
pcb/power/kicad/3dmodels/XT60PW-M.step

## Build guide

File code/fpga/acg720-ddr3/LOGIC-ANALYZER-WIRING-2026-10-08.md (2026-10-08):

# ACG720 / TY-OV5640 逻辑分析仪接线

2026-10-08。仅完成资料核对、可视化接线说明；没有编译、下载或采集，也没有验证实际线序。摄像头既有连接保留，逻辑分析仪探头并联。

可放大的两页位置图：[PDF](../../../output/pdf/ACG720-TY-OV5640-logic-analyzer-wiring.pdf)。预览：[开发板](../../../output/pdf/ACG720-TY-OV5640-wiring-1.png)、[摄像头模块](../../../output/pdf/ACG720-TY-OV5640-wiring-2.png)。

## 方向和接线

开发板正面朝上，HDMI 在左，DC 电源在右上。P7 在上边缘，左端内排的方形焊盘为 1 脚，左端外排为 2 脚。靠板边为偶数排 2/4/…/40，靠 FPGA 为奇数排 1/3/…/39。

TY 模块镜头朝你、排针在下，左上 GND 为 17 脚、左下 3V3 为 18 脚；右上 PWDN 为 1 脚、右下 NC 为 2 脚。背面视图左右反转。所有位置先与实物 1 脚标记及信号丝印核对。

| 通道 | 信号 | P7 针号 | TY 模块针号 |
| --- | --- | --- | --- |
| GND | 地 | 12 或 30 | 17 |
| CH0 | SCL | 14 | 15 |
| CH1 | SDA | 16 | 13 |
| CH2 | RST | 17 | 12 |
| CH3 | PWDN | 当前无对应控制脚，接模块端 | 1 |
| CH4 | VSYNC / VS | 13 | 16 |
| CH5 | HREF / HS | 15 | 14 |
| CH6/7 | 预留 | 不接 | 不接 |

每路在 P7 或模块端选择一个位置接，不必接两端。先接 GND；P7-11 为 5V、P7-29 为 3.3V，不能当作地，也不接分析仪。分析仪不向模块供电。P7 已占用时用夹钩或分线器并联，避免硬塞第二只杜邦母头或短接相邻焊点。数据线和 PCLK 原有连接保留。

用户已确认 TY 模块排针支持 3.3V；未改变开发板电压跳帽。分析仪的型号/输入规格仍未独立确定，按其标称允许的 3.3V 数字输入连接，不能从 USB VID/PID 推定耐压。

## 下一步及采集

1. 断电完成探头接线。此前程序只下载到 SRAM，因此断电会丢失配置，后续必须重新下载位流才能取得对应运行信号；不会写外部 Flash。
2. DDR 方向仍以第 38 章 800×480 测试输入为基线，先验收校准和完整帧读回，再接 OV5640 内部彩条，最后实景。这两页接线用于观察摄像头控制和同步，不把慢速分析仪当作 DDR 或完整 DVP 验证工具。
3. 含摄像头配置的程序运行后，在 Logic 选择实际连接的设备，启用 CH0～CH5，建议 8 MS/s、1 秒，添加 I2C 解码器 SCL=CH0、SDA=CH1，RST 下降沿触发。若没有 8 MS/s，选实际可用的 4 MS/s 或更高采样率。先开始采集再复位，或先设好触发再复位；不要错过初始化。
4. 现有摄像头主工程复位是 S4/B21；第 38 章原版是 S0/F15。原版第 38 章没有摄像头初始化逻辑，不能期待按 S0 出现 SCCB 事务。
5. I2C 默认 7-bit 地址应为 0x3C；查看 ACK、0x300A=0x56、0x300B=0x40 的真实读回。初始化后 RST 通常高、PWDN 通常低，VS/HS 持续活动。另存原始 .sal 文件，并记录所用位流 User Code、采样率和通道表；慢速同步可测帧周期/行活动，字节数与像素仍在 PCLK 域统计。

## 位置依据

- 开发板资料包：`06_硬件图纸/ACG720-138&60K通用原理图.pdf` 第 11 页 P7 电气编号，以及 `04_引脚功能信息/高云 ACG720-138&60K通用管脚分配表.xlsx`。
- 第 47 章教材 PDF 第 7 页原始实拍，正面 P7 右端为外排 40 / 内排 39；照片为 138K，按 60/138K 通用接口核对。
- [官方机械文件帖子](https://fpga.cn/forum.php?mod=viewthread&tid=28410)提供 ACX720-V3.DWG，左内排首焊盘为方形；机械布局与教材实拍的接口位置一致。它是官方 ACX720-V3 机械参考，尚未确认用户实物版本，不宣称已取得本机开发板全部 PCB 走线。
- 用户提供 `C:/Users/sc/Downloads/T-OV5640-PCB-V1.0-模型.pdf` 及模块实拍。
- [Saleae I2C 解码说明](https://www.saleae.com/support/protocol-analyzers/analyzer-user-guides/using-i2c)：默认显示 7-bit 地址。[采样率选项说明](https://www.saleae.com/support/logic-software/capturing-data/what-sample-rate-settings-are-available)：以所连接设备的采样率下拉列表为准。

为打开官方 DWG，下载了官方 LibreDWG 0.14 Windows x64 现成工具到 `.local/tools/libredwg/`，并使用现成 ezdxf / matplotlib 渲染机械图。没有自行实现 DWG 转换器。原文件和转换/渲染结果均保存在 `.local/review/20261008/`；转换器报告 MATERIAL/TABLESTYLE/MLEADERSTYLE 不稳定类警告，焊盘位置另经教材实拍核对。

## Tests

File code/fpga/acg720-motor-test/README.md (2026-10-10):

# ACG720 / AT8236 电机测试、持续启停与占空比循环

2026-10-10 为用户已经接好的现有电源板建立独立测试工程。器件为 GW5AT-LV60PG484AC1/I0、GW5AT-60B，使用板载 50 MHz，不依赖 DDR、PLL 或摄像头 IP。

当前板上为 **A717：50 kHz，左右各自按 0%→5%→……→100%→0% 循环，每档 500 ms，一轮约 10.5 秒**。S1/S2 分别开启、停止左/右轮循环，再次开启从 0% 开始；S0 停止两轮。已完成仿真、编译、实际引脚审查及 SRAM 下载，独立回读 `0x0000A717`；实物循环及停止表现待反馈。

A713 的 65% 左右持续启停已获用户确认；A714 的 1 kHz/80% 用户感觉未明显变快。A715 已编译但在下载前被用户的“直接上50kHz”要求替代，未上板。A716 的 50 kHz/80% 已下载，用户未提供实物结果，随后改为本次占空比循环要求。

此前 A712 的 1 kHz/50% 短时测试中，用户反馈“转了，亮了”，电机启动及编码器活动通过。A710、A711 的 25% 测试均未转动，对照支持此前启动激励不足；电流、最低启动占空比、转向和速度闭环尚未验证。各版本使用相同引脚，均默认停止、手动启动、S0 停止，只下载 SRAM。

| 版本 | 编译脚本 | PWM | 最高占空比 | 单次时限 | 实物结果 |
| --- | --- | --- | --- | --- | --- |
| A710 | `build.tcl` | 20 kHz | 25% | 2 秒 | 两轮均未转 |
| A711 | `build_1khz.tcl` | 1 kHz | 25% | 2 秒 | 两轮均未转，S1 时用户听到电机声音 |
| A712 | `build_start50.tcl` | 1 kHz | 50% | 1 秒 | 用户反馈电机转动、编码器活动灯亮 |
| A713 | `build_toggle.tcl` | 1 kHz | 65% | 按键启停，持续运行 | 用户确认左右启停正常 |
| A714 | `build_toggle80.tcl` | 1 kHz | 80% | 按键启停，持续运行 | 已下载；用户感觉未明显变快 |
| A715 | `build_toggle20k80.tcl` | 20 kHz | 80% | 按键启停，持续运行 | 已仿真及编译；用户改为 50 kHz，未下载 |
| A716 | `build_toggle50k80.tcl` | 50 kHz | 80% | 按键启停，持续运行 | 已下载，实际运行及速度待反馈 |
| A717 | `build_sweep.tcl` | 50 kHz | 0%～100%，每 500 ms 增加 5% 后回绕 | 按键启停，持续循环 | 已下载，实物循环及停止表现待反馈 |

排查过程、结论及复现方法见 [排查与实现文档](MOTOR-IMPLEMENTATION-2026-10-10.md)。下载过的 A712、A713、A714、A716、A717 位流及构建证据分别归档到 `release/` 同名目录；原厂资料和工具仍留在 `.local/`。

## 如何测试

1. 车轮架空，两只电机连接原有六针插座。12 V 电源接电源板，FPGA 由自己的电源供电，两板共地。编码器和驱动参考端使用 FPGA 开发板的 3.3 V。用户照片确认 USB J2 下的黄色排针是 P4；照片中 USB 在上、HDMI2 在下，最上端一对 P4-1 为经磁珠引出的 3.3 V，P4-2 为 GND，可分别连接电源板 L-6、L-5。
2. 下载本工程的 SRAM 位流后，先松开 S1、S2。约 100 ms 初始化及 20 ms 松键确认后可以开始。默认四个电机 IN 都为 0。
3. 当前 A717 下，按 **S1** 开始左轮占空比循环，松开后再按一次停止；**S2** 同样控制右轮。观察至少 12 秒可覆盖一轮；开始时为 0%，低占空比阶段可能不转，D1/D2 仍表示循环已开启。到 100% 时 D6 亮，随后占空比回到 0% 继续。两轮独立，允许同时循环；每次重新开启均从 0% 开始。
4. A713～A716 的历史版为固定最高占空比的持续运行，同样按键启停。**持续运行及循环版都不会自动超时。** 若使用历史 A712，则每次约 1 秒自动停止；A710/A711 为 2 秒。
5. **S0** 随时停止并复位。停止状态为 IN1=IN2=0，电机滑行，机械惯性不会由本程序立即消除。
6. 看电机是否旋转、对应的运行 LED 是否亮，以及编码器活动 LED 是否亮。转向暂不定义为车身“前进”，需要结合实际安装方向确认。

S1/S2 使用 20 ms 防抖；A713～A717 每键必须先稳定松开才允许下一次有效按下，长按不会反复启停，按住上电或释放 S0 不会自动启动。A710～A712 同时按下会拒绝启动，持续版及循环版则允许同时切换两轮。各版均不自动换向。

## LED 定义

这套灯态与原摄像头/DDR 自检不同。

| 灯 | 含义 |
| --- | --- |
| D0 | 启动延时结束，系统运行；是否允许启动还取决于按键是否已松开 |
| D1 | 左轮运行/循环已开启，期间常亮；A717 的 0% 阶段也亮 |
| D2 | 右轮运行/循环已开启，期间常亮；A717 的 0% 阶段也亮 |
| D3 | 左编码器 A/B 至少出现一次跳变，保持到下一次测试或 S0 |
| D4 | 右编码器 A/B 至少出现一次跳变，保持到下一次测试或 S0 |
| D5 | A713～A717 为两轮均停止；历史 A710～A712 为测试定时结束，不表示验证通过 |
| D6 | A717 为任一轮当前达到 100%；A713～A716 保留且灭；历史 A710～A712 为同时按键拒绝标志 |
| D7 | 1 Hz 心跳，每 0.5 秒翻转 |

编码器活动灯不代表转速、方向、四倍频计数或完整线序已经验证。复位后先建立采样基线，静态高电平不会被当成活动。持续版启动某轮只清除该轮活动记录，历史 A710～A712 开始一次测试时两侧都清零。停止后也可以手转电机检查活动。

## 与实际接线对应

| 顶层端口 | P7 | FPGA 球号 | 电源板 |
| --- | --- | --- | --- |
| left_in1 | 1 | A13 | L-1 / LAIN1 |
| left_in2 | 2 | A14 | L-2 / LAIN2 |
| left_enc_a | 3 | A15 | L-7 / LF_ENA |
| left_enc_b | 4 | A16 | L-8 / LF_ENB |
| right_in1 | 31 | F16 | R-5 / RAIN1 |
| right_in2 | 32 | E17 | R-6 / RAIN2 |
| right_enc_a | 33 | D20 | R-2 / RF_ENA |
| right_enc_b | 34 | C20 | R-1 / RF_ENB |

S0=F15、S1=A20、S2=B20，低有效；时钟 Y18=50 MHz。全部信号 IO 使用 LVCMOS33，实际 VCCIO 需为 3.3 V。AIN2 保持低，AIN1 送 PWM，适配 AT8236 的双 IN 接口；不要套用 TB6612 的独立 PWM/STBY 接法。未使用的 B 通道输入按接线图接电源板公共地。

完整板端针序与电源见 [接线文档](../../../doc/电机/ACG720与现有电源板接线_2026-10-10.md)。

## A710 默认实现及公共控制逻辑

- 50 MHz 计数生成 20 kHz PWM，每周期 2500 个时钟。前 50 ms 为 10%，50～100 ms 为 15%，100～200 ms 为 20%，之后为 25%，最高高电平时间 625 个时钟。
- 另生成 1 ms 时基，按键防抖、松键确认和单次 2 秒计时均用该时基。定时误差小于 1 ms。
- 上电计数器和状态寄存器初始化为停止；S0 异步清除状态并门控 PWM，复位释放经两拍同步。启动前必须检测到两个启动键已经稳定松开。
- 编码器与启动键各经过两级寄存器同步。编码器只做活动检查，不参与闭环，不根据无反馈自动加大 PWM。
- 本版将 P7-17/C14 摄像头复位保持低。独立测试 SRAM 位流暂时替代摄像头程序；原摄像头工程与通过位流保留不变，恢复原摄像头 SRAM 位流即可继续使用。

## 编译及仿真

在本目录执行：

```powershell
& 'C:/Gowin/Gowin_V1.9.12_x64/IDE/bin/gw_sh.exe' './build.tcl'

$motorIcarus = '../acg720-ddr3/.local/tools/iverilog/bin'
New-Item -ItemType Directory -Force '.local' | Out-Null
& "$motorIcarus/iverilog.exe" -g2012 -Wall -s acg720_motor_test_tb -o '.local/motor_test.vvp' 'rtl/acg720_motor_test.v' 'tests/acg720_motor_test_tb.v'
& "$motorIcarus/vvp.exe" '.local/motor_test.vvp'

& 'C:/Users/sc/.cache/codex-runtimes/codex-primary-runtime/dependencies/python/python.exe' -X utf8 'tests/audit_build.py'
```

`tests/audit_build.py` 核对实际 PNR 报告中的 21 个顶层端口、方向、全部 3.3 V IO、四路驱动输出的下拉，以及 setup/hold 违反数和位流 User Code，结果保存在 `.local/build-audit-20261010.json`。

## A710 验证及排查记录

- Icarus 仿真通过：配置时按住启动键、防抖、左右选择、25% PWM 周期、编码器基线与映射、单次超时、按住不重复、S0 在 PWM 高期间异步停止、复位释放不重启、同时按键拒绝及重新启动。
- Gowin V1.9.12 完成综合、布局布线和位流生成；21 个实际端口与接线一致。
- 50 MHz 时序：setup/hold 违反端点均为 0；报告 Fmax 为 166.268 MHz，最差 setup slack 13.986 ns、hold slack 0.275 ns。异步外部输入路径已明确约束；这不替代实物信号质量验证。
- User Code：`0x0000A710`。
- 位流：`impl/pnr/acg720_motor_test.fs`。
- SHA256：`82247E0D4383C2208AFEDE85997A5DAAAC3058376CB8DF465B90D2E36B1B7ADA`。
- SRAM 下载已完成：Gowin USB Cable(FT2CH)，USB location=548，FPGA ID=`0x0001481B`；operation_index=2 下载 100%，User Code=`0x0000A710`，Status=`0x70022020`。随后再次独立读取 User Code 和 Status，结果一致，外部 Flash 未写。
- 下载前实际读取的 User Code 为 `0x0000BC6C`，不再沿用历史记录中的 `0xAF89` 作为当时板上状态。已验证摄像头实景 `0xAF89` 源码及位流仍保留在 `../acg720-ddr3/.local/framebuffer-first/ch38-camera-live/`。
- 首次实物反馈：两只电机均未转动；S1/S2 分别使 FPGA D1/D2 亮，随后运行灯灭、D5 亮，D3/D4 均未亮。运行灯和完成灯只能证明控制状态及定时已执行，不能证明驱动端已收到信号或电机已供电；本版会在约 2 秒后自动停止，无需再按一次启动键。
- 用户随后反馈电源板电源指示灯未亮。当前优先检查电机 VM 电源通路：原理图为 CN1 的 VCCIN → SW2 → VM → 两个 AT8236 模块；LED1 由 VM 供电，位号 D1 则为 TVS，不是指示灯。尚无 VM 或 3.3 V 实测读数，因此暂不能确定为开关、供电、焊接、线束或 PWM 启动力矩问题。
- 用户进一步确认 SW2 已连通、12 V 可以提供；后续不再要求安装或重复操作 SW2。仍需区分供电源有 12 V 与驱动模块 VM/GND 端实际测到 12 V，并测 L-6/L-5 的 3.3 V。停止后手转车轮、观察 D3/D4，可独立核查编码器供电及反馈通路，不以未转电机的编码器灯灭判定输入故障。
- 3.3 V 测量点为 L-6 对 L-5：按用户 PCB 截图方向，右侧上排标 L 的八针接口从左到右为 1～8，黑表笔接第 5 针 GND，红表笔接第 6 针 3.3 V。另需测驱动模块标注 VM 对 GND，正常应接近外部 12 V 电源电压；不要把 VM 接到 FPGA IO 或 3.3 V。
- 用户实测反馈：L-6 对 L-5 为 3.3 V，驱动 VM 为 12 V；停止后手转左右轮，D3/D4 仍均未亮。现阶段不能认定电机或编码器损坏，也不能把故障仅归因于 25% PWM。复核官方 P7 管脚和实际约束一致；待测左轮 L-1 对 L-5 在 S1 测试期间的 PWM 直流平均值（平台预计约 0.825 V）、L-7/L-8 对 L-5 在手转停位时的高低电平，以及下方左电机六针插座 2 对 5 的编码器电源。板端针序不代表电机线束顺序已确认，MG513 霍尔/GMR 版本的编码器供电极性需结合实物核对。
- 同日补核 [WHEELTEC MG513X 官方产品页](https://www.wheeltec.net/product/html/?223.html)：[编码器参数图](https://www.wheeltec.net/kindeditor/attached/image/20251121/20251121160212_30101.jpg) 明确输出带上拉到编码器 VCC，供电范围 3.3～5 V。因此不能在尚未测量 A/B 电平时将无反馈归因于“必须补外部上拉”；[实物类型图](https://www.wheeltec.net/kindeditor/attached/image/20251121/20251121160211_88837.jpg) 可辅助辨认裸露霍尔板与带后盖 GMR 版本，最终仍以用户实物/线序为准。
- 后续实测：S1 运行时 L-1 对 L-5 约 0.8 V，证明控制线在电源板 L 排针端存在与当前 PWM 相符的直流平均电压；左电机六针插座 2 对 5 为 3.3 V。手转左轮 L-7 可到约 2.3 V、L-8 持续约 2.3 V，尚待确认停止后的高低电平和 FPGA 端电平，不能用平均读数代替波形。
- 用户新增裸露霍尔编码器照片，插座旁丝印从上到下为电机+、编码器 GND、B 相、A 相、编码器 5V、电机-。用户说明对应右下方左电机插座从右到左，故实际信号对应为 6/5/4/3/2/1，与板端定义一致；供电正极位置正确，本批次 3.3 V 的实际工作状态仍待验证。未以此推断焊接导通、驱动输出或编码器功能已通过。
- S1 测试期间，用户测左电机六针插座 6 对 1 的最高直流电压约 0.05 V，电机未转。该读数是 20 kHz 快衰减 PWM 下万用表的平均测量，不能直接替代输出波形，也不能证明模块完全不工作。电机功率来自 VM=12 V，编码器供电 3.3 V 与模块参考输入不等同于电机供电；不能把共用 3.3 V 网改接 5 V。模块本体的 VCC、AIN1/AIN2 实测值仍待确认。

## 1 kHz 频率对照工程（A711）

为排查低占空比快衰减模式下的启动电流不足，新增 `acg720_motor_test_1khz.gprj` 和 `rtl/acg720_motor_test_1khz.v`。包装顶层只将原控制器的 `PWM_HZ` 设为 1000，沿用全部原管脚、IO 电压、编码器输入偏置、10%→25% 爬升、单轮选择、2 秒超时和 S0 停止逻辑。原 A710 工程仍为 20 kHz，可随时重新编译；已验证 A710 位流及报告另外保留在忽略目录 `.local/history/A710/`。

1 kHz 时，每周期为 50000 个 50 MHz 时钟，25% 的高电平为 12500 个时钟，即 250 µs；A710 同占空比的高电平为 12.5 µs。更长的脉冲用来检验电机电流建立和芯片唤醒条件，测试结果尚未证明这是不转的根因。快衰减的关断阶段包含电感续流，电机两端直流平均值不能简单认定为 `VM × 占空比`。

编译和检查：

```powershell
& 'C:/Gowin/Gowin_V1.9.12_x64/IDE/bin/gw_sh.exe' './build_1khz.tcl'
& 'C:/Users/sc/.cache/codex-runtimes/codex-primary-runtime/dependencies/python/python.exe' -X utf8 'tests/audit_build.py' --variant 1khz
```

专用仿真 `tests/acg720_motor_test_1khz_tb.v` 已验证包装顶层的 1 kHz 周期、准确 25% 占空比、单轮输出、定时结束、按住不重复及 S0 异步停止。User Code 为 `0x0000A711`；位流路径为 `impl/pnr/acg720_motor_test_1khz.fs`。编译、实际 PNR 审查及 SRAM 下载的完成情况需按后续记录确认。

A711 完成记录：

- Gowin V1.9.12 编译完成，21 个实际 PNR 管脚通过审查；50 MHz setup/hold 违反端点均为 0，Fmax=188.612 MHz。
- 位流 SHA256：`81C8BF4A7A41FAAC8D94A18ECF846A082514C6449708F9C8F36D9EFFEE989CF3`。
- 下载前独立读取 User Code 为 `0x0000A710`。使用 operation_index=2 下载 A711 至 SRAM，进度 100%；下载后独立读取 User Code=`0x0000A711`、Status=`0x70022020`，外部 Flash 未写。
- 用户反馈 A711 两轮仍均不转；S1 时明显听到电机声音。用户确认此前测量的是 PCB 图右侧、L 上方的左轮 AT8236 模块，本体 VCC 对 GND 为 3.3 V，AIN1/AIN2 未测出电压。该输入读数与此前 L-1 的约 0.8 V 不一致；两秒窗口、表笔接触、通道/安装方向或导通问题仍需区分。声音不能证明输出正常，频率降低也未解决故障。
- A711 位流、报告、审查 JSON 和当时 RTL 已另存 `.local/history/A711/`。后续公共控制器添加占空比参数后，A710/A711 默认仍为 25%，仿真回归均通过；旧位流的构建证据以对应历史源文件和审查哈希为准。
- 编译、审查、下载及回读证据保存在 `.local/build-1khz-20261010.log`、`.local/build-audit-1khz-20261010.json`、`.local/sram-1khz-program-20261010.log`、`.local/after-1khz-usercode-20261010.log`、`.local/after-1khz-status-20261010.log`。

## 50% 短时启动对照工程（A712）

新增 `acg720_motor_test_start50.gprj`、`rtl/acg720_motor_test_start50.v` 和 `build_start50.tcl`。公共控制器新增默认值为 25 的 `DUTY_PERCENT` 参数；A712 包装顶层显式设置为 50，PWM 仍为 1 kHz，单次时限缩短至 1000 ms。爬升阶段依次为 10%（前 50 ms）、25%（50～100 ms）、40%（100～200 ms）、50%（之后至超时）。选择、松键确认、S0 停止、编码器采样和全部管脚保持原逻辑。

这次对照用于检验启动电流/扭矩不足的可能性。用户随后反馈“转了，亮了”，因此 A712 已解决本次短时测试不转的问题。此前仅将频率从 20 kHz 降到 1 kHz 并未解决；在同为 1 kHz 的对照中，提高最高占空比及爬升阶段后启动成功。未测量实际电流及桥输出波形，不将电感、摩擦、限流或具体启动阈值记为已经确认。若后续复测仍只有声音、不转，应核对模块安装和导通，不直接继续提高占空比。

编译及审查：

```powershell
& 'C:/Gowin/Gowin_V1.9.12_x64/IDE/bin/gw_sh.exe' './build_start50.tcl'
& 'C:/Users/sc/.cache/codex-runtimes/codex-primary-runtime/dependencies/python/python.exe' -X utf8 'tests/audit_build.py' --variant start50

$motorIcarus = '../acg720-ddr3/.local/tools/iverilog/bin'
& "$motorIcarus/iverilog.exe" -g2012 -Wall -DSTART50_TEST -s acg720_motor_test_1khz_tb -o '.local/motor_test_start50.vvp' 'rtl/acg720_motor_test.v' 'rtl/acg720_motor_test_start50.v' 'tests/acg720_motor_test_1khz_tb.v'
& "$motorIcarus/vvp.exe" '.local/motor_test_start50.vvp'
```

A712 完成记录：

- A710 安全测试、A711 的 1 kHz/25% 测试回归通过；A712 专用包装顶层测试验证准确 1 kHz/50%、单轮选择、超时、按住不重复及 S0 异步停止。仿真缩短运行参数以加快测试；实际编译顶层使用 `RUN_MS=1000`。
- 首次高云编译在布线阶段异常退出（退出码 `-1073741819`）；保留 `.local/build-start50-20261010-attempt1-crash.log`，重新编译成功生成位流。未下载失败构建的产物。
- Gowin V1.9.12 完成综合、布局布线和位流生成，21 个实际 PNR 管脚核对通过；50 MHz setup/hold 违反端点均为 0，Fmax=183.823 MHz。
- 位流 `impl/pnr/acg720_motor_test_start50.fs`，User Code=`0x0000A712`；SHA256=`84B3E192B543C1EF72AAC51B141E789BF2733C6563BE163DEAA7D5FE1A0DA7FF`。
- 下载前独立读取 User Code=`0x0000A711`；operation_index=2 SRAM 下载完成后，独立读取 User Code=`0x0000A712`、Status=`0x70022020`。外部 Flash 未写。
- 用户在 S1/S2 逐轮测试及 D3/D4 活动灯观察提示后，于 2026-10-10 回复“转了，亮了”。按该反馈记录电机转动及编码器活动通过；用户未提供逐轮速度、方向、A/B 波形或脉冲数。D1/D2 只表示测试状态，D5 只表示时限结束；新测试会清除两侧上次活动记录。
- 证据保存在 `.local/sim-start50-20261010.log`、`.local/build-start50-20261010.log`、`.local/build-audit-start50-20261010.json`、`.local/sram-start50-program-20261010.log`、`.local/after-start50-usercode-20261010.log`、`.local/after-start50-status-20261010.log`。

本工程没有电流测量、堵转判定、方向核对或速度闭环，首次验证应架空、逐轮进行。只下载 SRAM，不写外部 Flash，断电后本次配置丢失；外部 Flash 原有程序的行为不受本程序约束。

## 持续运行与再次按键停止（A713）

用户在 A712 启动通过后要求 S1/S2 分别持续驱动左/右电机，再按一次停止，并提高速度。新增独立控制器 `rtl/acg720_motor_toggle.v`、`acg720_motor_toggle.gprj` 和 `build_toggle.tcl`，保留 A712 的源码及位流字节。

- **S1** 每次有效按下切换左轮运行/停止；**S2** 独立切换右轮。两轮可以同时运行；不会自动换向。
- 上电和 S0 后默认停止，各键必须先稳定松开再允许下一次按下。长按只切换一次，20 ms 防抖；**S0** 不等待防抖或时钟，立即停止两侧 PWM。停止仍为滑行。
- 使用已通过的 1 kHz，将最高占空比从 50% 提高到 **65%**。前 50 ms 为 10%，50～100 ms 为 25%，100～200 ms 为 40%，200～300 ms 为 50%，300～400 ms 为 60%，之后保持 65%，直到再次按对应键或 S0。
- 两侧独立记录爬升进度。编码器灯仍为活动锁存；启动某轮时只清除该轮活动历史，不影响另一轮。没有一秒或两秒超时，也没有速度 PID。
- LED：D0=系统就绪，D1=左轮运行，D2=右轮运行，D3/D4=各轮编码器活动，**D5=两轮均停止**，D6=保留且灭，D7=心跳。D5 不再表示测试超时。

编译 `build_toggle.tcl`，实际顶层为 `acg720_motor_toggle`，User Code=`0x0000A713`；审查使用 `tests/audit_build.py --variant toggle`。专用仿真 `tests/acg720_motor_toggle_tb.v` 验证准确 1 kHz/65%、持续超过旧两秒时限、长按无重复、再次按下停止、两侧独立及同时运行、编码器历史独立清除、S0 在时钟之间停止，以及复位时按住不启动。

65% 是 PWM 输出设定，实际转速仍由供电、负载和电机决定，需用户观察；没有把实际速度增幅当作已测得数据。

A713 完成记录：

- Icarus 专用仿真通过，已覆盖上述持续运行和启停行为；不重复编译或改写 A712 的已通过源码。
- Gowin V1.9.12 编译成功，21 个实际端口与接线一致，50 MHz setup/hold 违反端点均为 0，Fmax=184.374 MHz。
- 位流 `impl/pnr/acg720_motor_toggle.fs`；SHA256=`A144E8D407B4D39044E1852272FFC0E007B97EFCCD6E736DA8F3A85F61831307`。
- 下载前独立读取 `0x0000A712`；operation_index=2 SRAM 下载完成，随后独立读取 User Code=`0x0000A713`、Status=`0x70022020`。未写外部 Flash。
- 用户在持续启停提示后回复“都可以了，再调快点，调到80%”，确认 A713 左右启停正常。没有提供转速、电流或长时间负载数据。
- 本次源码、位流及证据归档至 `release/A713/`。源码构建入口为 `build_toggle.tcl`，审查为 `tests/audit_build.py --variant toggle`。

## 用户指定 80% 的持续运行版（A714）

新增包装顶层 `rtl/acg720_motor_toggle_80.v`，复用 A713 控制器，仅将 `DUTY_PERCENT` 显式设为 **80**。顶层 `acg720_motor_toggle_80` 使用 `build_toggle80.tcl` 编译，User Code=`0x0000A714`；审查为 `tests/audit_build.py --variant toggle80`。S1/S2 独立持续启停、S0 停止、1 kHz 周期、400 ms 爬升和编码器记录规则均沿用 A713；平台高电平为每周期 40000/50000 个时钟，即 800 µs。

仿真以 `-DTOGGLE80_TEST` 编译同一持续启停测试，实际检查 80/100 的平台 PWM，并覆盖长按、持续运行、第二次停止、独立两轮和 S0 停止。A713 的已通过源码及记录没有修改，便于对照及恢复。构建/下载和实物结果按后续完成记录确认。

A714 完成记录：

- 仿真通过，21 个实际 PNR 管脚与接线一致；50 MHz setup/hold 违反端点均为 0，Fmax=170.122 MHz。
- 位流 `impl/pnr/acg720_motor_toggle_80.fs`；SHA256=`4E65CDF93D7B43819BFF3ACB35E94D34A5DE69E4DF51D26C7BFD1F11E373EC23`。
- 下载前独立读取 `0x0000A713`，SRAM 下载后独立读取 User Code=`0x0000A714`、Status=`0x70022020`。外部 Flash 未写；证据归档 `release/A714/`。
- 用户反馈“感觉并没有变快，除了调整占空比，是不是频率也要设置一下？”。未获得实测转速，因此只记录没有主观明显加速，不能确认 65% 和 80% 实际转速完全相同。

## 20 kHz、80% 频率对照（A715）

A715 包装顶层 `rtl/acg720_motor_toggle_20khz_80.v` 复用同一持续控制器，将频率从 1 kHz 改为 20 kHz，保持 80%、400 ms 爬升、按键和 IN1=PWM/IN2=0 快衰减接法。一个周期 2500 个 50 MHz 时钟；平台高电平 2000 个时钟（40 µs），低电平 500 个时钟（10 µs）。编译 `build_toggle20k80.tcl`；审查 `tests/audit_build.py --variant toggle20k80`，User Code=`0x0000A715`。

本次对照不承诺加速。AT8236 原厂手册第 3 页允许控制 PWM 至 100 kHz，第 5 页说明快/慢衰减接法，第 6 页说明 VREF/ISEN 决定电流阈值；目前使用快衰减。频率会影响电流建立、纹波和噪声，而稳态转速还受负载、供电及电流限制影响；没有电流、波形或转速数据时，不将其中某项认定为根因。TI 的 [PWM 与衰减接口说明](https://e2e.ti.com/support/motor-drivers-group/motor-drivers/f/motor-drivers-forum/963987/faq-what-interface-ph-en-or-pwm-to-use-for-controlling-brushed-dc-motors) 和 [电流续流及衰减应用报告](https://www.ti.com/lit/an/slva321/slva321.pdf) 用于核对一般原理，不替代 AT8236 本体规格。

仿真使用 `-DTOGGLE20K80_TEST`，每 1 ms 同时核对 PWM 上升沿数和高电平占比，避免只验证平均占空比而遗漏频率；还覆盖持续启停和 S0 停止。实物转速变化需要后续观察或编码器计数比较。

A715 仿真及编译完成，但下载前用户要求“直接上50kHz”，因此 **A715 未下载**，不记任何实板结果。源码和构建入口保留供后续对照。

## 用户指定 50 kHz、80%（A716）

包装顶层 `rtl/acg720_motor_toggle_50khz_80.v` 显式设 `PWM_HZ=50000`、`DUTY_PERCENT=80`，复用已验证的持续启停控制器。板载 50 MHz 下每周期 1000 个时钟，高电平 800 个时钟（16 µs），低电平 200 个时钟（4 µs）。400 ms 爬升、S1/S2 启停、S0、编码器及接线保持原实现。

使用 `build_toggle50k80.tcl` 和 `tests/audit_build.py --variant toggle50k80`，User Code=`0x0000A716`。仿真 `-DTOGGLE50K80_TEST` 使用可精确表示 80% 的测试时钟，每毫秒检查 50 个上升沿及 80% 高电平，并验证持续运行和按键停止。提高频率不是转速提高的证明，实际结果另记。

A716 完成记录：

- 专用仿真通过，21 个实际 PNR 端口与接线一致；50 MHz setup/hold 违反端点均为 0，Fmax=188.257 MHz。
- 位流 `impl/pnr/acg720_motor_toggle_50khz_80.fs`；SHA256=`9C85F5250EF1EF790036797F47320E03269E792131773B30437A78106287890B`。
- 下载前独立读取 `0x0000A714`；SRAM 下载后独立读取 User Code=`0x0000A716`、Status=`0x70022020`，未写 Flash。
- 已请用户观察实际启停、声音及转速变化，目前待反馈。50 kHz 对照的输出设置已确认，尚未确认提速。
- 位流、源码哈希、实际 PNR/时序、仿真、构建及下载/回读记录保存在 `release/A716/`。

A716 复现：

```powershell
& 'C:/Gowin/Gowin_V1.9.12_x64/IDE/bin/gw_sh.exe' './build_toggle50k80.tcl'
& 'C:/Users/sc/.cache/codex-runtimes/codex-primary-runtime/dependencies/python/python.exe' -X utf8 'tests/audit_build.py' --variant toggle50k80

$motorIcarus = '../acg720-ddr3/.local/tools/iverilog/bin'
& "$motorIcarus/iverilog.exe" -g2012 -Wall -DTOGGLE50K80_TEST -s acg720_motor_toggle_tb -o '.local/motor_toggle50k80.vvp' 'rtl/acg720_motor_toggle.v' 'rtl/acg720_motor_toggle_50khz_80.v' 'tests/acg720_motor_toggle_tb.v'
& "$motorIcarus/vvp.exe" '.local/motor_toggle50k80.vvp'
```

## 0%～100% 占空比循环（A717，当前板上）

用户要求从最低到最高占空比循环，按键开始、再按一次停止。新增独立顶层 `rtl/acg720_motor_sweep.v`、工程 `acg720_motor_sweep.gprj` 和脚本 `build_sweep.tcl`，保留 A712～A716 的源码及已下载位流。

- 频率保持 **50 kHz**，板载 50 MHz 下每周期 1000 个时钟，周期 20 µs。每 500 ms 增加 5%，高电平门限依次为 0、50、100、……、1000 个时钟；100% 保持连续高电平，500 ms 后回到 0%。21 档合计约 10.5 秒，持续重复。
- 左右各自保存毫秒计数和占空比门限。S1/S2 只翻转对应循环状态，再次启动时对应门限及计时清零。两轮可以同时运行，停止一轮不影响另一轮。新门限在 PWM 周期边界生效，避免中途改变脉冲宽度；生效延迟不超过一个 PWM 周期。
- 继承两级输入同步、20 ms 防抖、稳定松键确认、配置及 S0 后默认停止、S0 异步门控输出、编码器活动基线及独立清除。IN2 始终为 0，无自动换向。D6 表示任一轮当前为 100%，D1/D2 在循环的 0% 阶段仍亮。
- 低占空比阶段电机可能静止，高档阶段是否更快需实物观察；本次不以活动灯量化转速。占空比降为 0% 或按键停止后电机仍可能因惯性滑行。

复现命令：

```powershell
$motorIcarus = '../acg720-ddr3/.local/tools/iverilog/bin'
New-Item -ItemType Directory -Force '.local' | Out-Null
& "$motorIcarus/iverilog.exe" -g2012 -Wall -s acg720_motor_sweep_tb -o '.local/motor_sweep.vvp' 'rtl/acg720_motor_sweep.v' 'tests/acg720_motor_sweep_tb.v'
& "$motorIcarus/vvp.exe" '.local/motor_sweep.vvp'
& 'C:/Gowin/Gowin_V1.9.12_x64/IDE/bin/gw_sh.exe' './build_sweep.tcl'
& 'C:/Users/sc/.cache/codex-runtimes/codex-primary-runtime/dependencies/python/python.exe' -X utf8 'tests/audit_build.py' --variant sweep
```

A717 完成记录：

- 专用仿真保持真实 50 kHz，将模拟时钟改为 5 MHz、每档缩短为 4 ms、防抖为 2 ms。逐档统计输出的高电平和上升沿，覆盖左轮两轮完整循环、右轮完整循环及回绕、0% 无脉冲、100% 无低脉冲、独立启停与重新从 0% 开始、长按及短暂抖动、编码器历史独立清除、S0 在时钟边沿间停止。实际编译参数仍为 50 MHz、500 ms、20 ms。
- 初次编译出现加法进位截断提示；改为显式保留加法进位，再截取经边界约束的门限，仿真重新通过。正式构建日志无该位宽提示；没有下载初次产物。1000 需要 10 位，门限最大合法值为 1000，最后一次增加为 950+50，到 1000 后直接归零。
- Gowin V1.9.12 完成综合、布局布线和位流生成，实际 21 个管脚与原接线一致；50 MHz setup/hold 违反端点均为 0，Fmax=184.331 MHz。
- 位流 `release/A717/acg720_motor_sweep.fs`，User Code=`0x0000A717`；SHA256=`B54E13D91CA2C3A3F0A788FA0ACB1AB27E2A2DB854872CBFF902E770F6D48BC7`。
- 下载前独立读取 `0x0000A716`。使用 operation_index=2 下载至 SRAM，进度 100%；随后独立读取 User Code=`0x0000A717`、Status=`0x70022020`。外部 Flash 未写。
- 构建、仿真、实际 PNR/时序、源码哈希和下载/回读记录归档到 `release/A717/`。本次程序及下载验证已完成，实物循环、再次按键停止和转速表现待用户观察。

断电后本次 A717 SRAM 配置丢失，重新供电加载外部 Flash 原有程序。恢复固定占空比对照可重新下载 `release/A716/` 或已实测启停正常的 `release/A713/` 位流。

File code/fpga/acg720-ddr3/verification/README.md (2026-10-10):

# 验证快照与交付包

## 本机单帧自检快照

`2026-10-08/` 保存当日对应位流的结果，LED 状态来自用户实物反馈，SHA256 来自对应文件。静态版逐像素比较，彩条与实景版验证完整帧尺寸并比较两端 CRC。

这些是历史记录，不表示今后任何新构建、重新下载或断电启动已经通过。位流和原始工具日志留在本机 `.local`，本轮只写 SRAM，没有写配置 Flash，也没有验证连续 HDMI 图像。

`live-build-audit.json` 保留彩条/实景的两个源码差异和未完成时序签核的事实。完整过程见 [排查与实现文档](../DDR3-FRAMEBUFFER-IMPLEMENTATION-2026-10-08.md)。

## 导入的实景 HDMI 交付包

2026-10-10 合入用户提供的 `verified-20261008.zip`，保存于 [verified-20261008/](verified-20261008/README.md)。包含双帧区 HDMI 位流、正式 PNR 报告、仿真日志、HDMI 实景照片、用户反馈和原工程提交摘要，原始 30 个文件全部保留原字节并核对哈希。

该包记录 HDMI 实景显示功能通过；镜头移动后的刷新、长时间稳定性和断电冷启动未单独确认。正式时序摘要仍有 101 个 setup、29 个 hold 违反端点。完整 RTL 和构建脚本未包含在包内，不能只凭该包重建源码工程。

原始 `MANIFEST.json` 中 `SHA256SUMS` 的旧条目与实际文件不符，其余条目及 `SHA256SUMS` 内 29 项校验均通过；新增 `IMPORT-MANIFEST.json` 记录全部实际文件和差异。详细来源、位流身份及证据范围见导入目录 README。

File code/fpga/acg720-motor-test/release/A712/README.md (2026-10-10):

# A712 已验证电机测试快照

2026-10-10 使用本目录位流进行 SRAM 单轮测试。User Code 为 `0x0000A712`，独立读取 Status 为 `0x70022020`。用户在 S1/S2 逐轮测试及 D3/D4 观察提示后回复“转了，亮了”。

参数为板载 50 MHz、PWM 1 kHz、10%→25%→40%→50% 爬升、单次一秒。默认停止；S1 测左轮、S2 测右轮、S0 停止。编码器灯只确认活动，不表示转速、方向或两相计数通过。只写 SRAM，断电后该配置丢失。

`acg720_motor_test_start50.fs` 完全由本项目独立电机 RTL 构建，不含摄像头、DDR 或原厂加密 IP。位流及记录保留原始字节，Git 不转换换行符。

SHA256：`84B3E192B543C1EF72AAC51B141E789BF2733C6563BE163DEAA7D5FE1A0DA7FF`。

同目录保留实际布局布线报告、时序报告、21 管脚和时序审查 JSON、三个版本的仿真通过日志、A712 构建日志、下载和独立回读日志。首次布线崩溃日志及 A710/A711 历史位流仍保留在本机忽略目录 `.local/`。

复现源码及参数见 [工程 README](../../README.md)，定位方法与结论见 [排查与实现文档](../../MOTOR-IMPLEMENTATION-2026-10-10.md)。下载时选择 GW5AT-60B 和 **SRAM Program**；本快照没有执行或验证外部 Flash 固化。

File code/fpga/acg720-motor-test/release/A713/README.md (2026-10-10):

# A713 持续启停构建与下载快照

2026-10-10 根据用户要求，将 S1/S2 改为左右轮独立持续启停，再按一次停止，允许同时运行；最高占空比提高为 65%，PWM 为 1 kHz，启动爬升 400 ms。默认停止，长按不会重复翻转，S0 停止两轮。没有单次超时。

仿真、实际引脚和时序检查已通过，SRAM 下载后独立读取 User Code=`0x0000A713`、Status=`0x70022020`。用户回复“都可以了，再调快点，调到80%”，确认左右持续启停正常。没有量化转速、电流或长时间负载数据；后续 80% 为 A714。

位流为本项目独立 RTL 构建的 `acg720_motor_toggle.fs`；SHA256=`A144E8D407B4D39044E1852272FFC0E007B97EFCCD6E736DA8F3A85F61831307`。同目录包含实际 PNR/时序报告、五个构建输入的哈希、仿真日志、编译日志、下载和独立回读日志。Git 保留其原始字节。

仅操作 SRAM，断电后丢失；未修改外部 Flash。LED 含义及使用步骤见 [工程 README](../../README.md)，实现及定位过程见 [排查与实现文档](../../MOTOR-IMPLEMENTATION-2026-10-10.md)。已实测可启动的短时 A712 快照见 [A712](../A712/README.md)。

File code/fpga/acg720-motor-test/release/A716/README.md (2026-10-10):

# A716 50 kHz / 80% 构建及下载快照

2026-10-10 根据用户“直接上50kHz”的要求构建。沿用 A713 控制器，显式设置 50 kHz、80%，400 ms 爬升；S1/S2 独立持续启停，再按一次停止，允许同时运行，S0 停止两轮。默认停止，长按不会重复，无自动超时。

仿真通过，每 1 ms 检查 50 个 PWM 上升沿和 80% 高电平，并覆盖独立启停及 S0。21 个实际管脚和 50 MHz 时序核对通过，setup/hold 违反为 0，Fmax=188.257 MHz。SRAM 下载后独立读取 User Code=`0x0000A716`、Status=`0x70022020`。实际启停、噪声及转速变化仍待用户观察，不记录提速已经通过。

位流 `acg720_motor_toggle_50khz_80.fs`，SHA256=`9C85F5250EF1EF790036797F47320E03269E792131773B30437A78106287890B`。同目录保留原始构建、仿真、实际 PNR/时序、源码哈希及下载/回读记录，Git 不转换其字节。

只写 SRAM，断电后丢失，未写 Flash。A715 的 20 kHz 版没有下载。使用说明见 [工程 README](../../README.md)，完整过程见 [排查与实现文档](../../MOTOR-IMPLEMENTATION-2026-10-10.md)。

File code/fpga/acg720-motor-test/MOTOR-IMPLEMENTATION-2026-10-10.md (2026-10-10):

# ACG720 电机启动排查与实现

记录日期：2026-10-10。硬件为小梅哥 ACG720 / GW5AT-60B、用户现有嘉立创 EDA 电源板、AT8236 模块及 MG513 编码电机。

## 结果与证据范围

A712 已解决本次短时测试中电机不转的问题。程序为 1 kHz PWM，启动爬升至最高 50%，单次一秒后停止。下载及独立回读得到 User Code `0x0000A712`、Status `0x70022020`。用户在 S1/S2 逐轮测试及 D3/D4 观察提示后回复“转了，亮了”。

这条反馈确认电机能够启动、FPGA 能检测到编码器活动。未提供逐轮转速、方向、A/B 波形或脉冲数，不能将其扩展为编码器两相完整验证、闭环调速通过或整车落地运行通过。所有实物观察均来自用户，工具负责构建、引脚审查、下载及寄存器回读。

当前板上已更新到 A717 占空比循环版，频率为 50 kHz，按 0% 到 100% 每 500 ms 增加 5%，回到 0% 重复。S1/S2 各自启停，S0 停止两轮；下载及独立回读通过，实物循环表现待用户确认。下面保留各次对照结果，A717 实现详见末节。

## 接线与供电

使用用户 2026-10-09 的单页原理图及 PCB，接口名称和左右位置以该实物为准。PCB 图中 R 在左，L 在右，两排八针接口均从方形焊盘开始，从左到右数 1～8。

| 信号 | FPGA P7 | FPGA 球号 | 电源板端 |
| --- | --- | --- | --- |
| 左轮输入 1 / PWM | 1 | A13 | L-1 / LAIN1 |
| 左轮输入 2 / 固定低 | 2 | A14 | L-2 / LAIN2 |
| 左轮编码器 A | 3 | A15 | L-7 / LF_ENA |
| 左轮编码器 B | 4 | A16 | L-8 / LF_ENB |
| 右轮输入 1 / PWM | 31 | F16 | R-5 / RAIN1 |
| 右轮输入 2 / 固定低 | 32 | E17 | R-6 / RAIN2 |
| 右轮编码器 A | 33 | D20 | R-2 / RF_ENA |
| 右轮编码器 B | 34 | C20 | R-1 / RF_ENB |

FPGA 使用独立电源；电源板电机 VM 使用外部 12 V，两板共地。电源板没有这路共用 3.3 V 的稳压来源，由 FPGA 提供编码器电源和模块 VCC 参考。用户实物中 USB J2 下黄色排针为 P4，照片上端 P4-1 为 3.3 V、P4-2 为 GND，分别连接 L-6、L-5。L-6/R-3 同属 3.3 V，L-5/R-4 同属 GND。未用 B 通道输入接本板 GND。

用户已测 L-6 对 L-5 为 3.3 V、模块 VM 对 GND 为 12 V、模块 VCC 对 GND 为 3.3 V；SW2 已连通。电机六针插座从左到右为 AOUT2、编码器 VCC、A 相、B 相、GND、AOUT1。电机照片丝印及用户线束对应说明与这个顺序一致。

编码器照片标有 5V，但在本次 3.3 V 接线不变的情况下，A712 转动后活动灯已亮，因此不需要为了本次启动测试改接 5 V。电机功率来自 12 V 的 VM，共用 3.3 V 不是电机供电。该网络还连着 FPGA 电源和驱动参考端，不可整体改接 5 V。完整针序与图纸见 [接线文档](../../../doc/电机/ACG720与现有电源板接线_2026-10-10.md)。

## 如何定位本次不转的问题

| 版本 | PWM | 爬升至最高占空比 | 时限 | 用户实物反馈 |
| --- | --- | --- | --- | --- |
| A710 | 20 kHz | 10% → 15% → 20% → 25% | 2 秒 | 两轮均不转，编码器灯未亮 |
| A711 | 1 kHz | 10% → 15% → 20% → 25% | 2 秒 | 两轮仍不转，S1 时能听到声音 |
| A712 | 1 kHz | 10% → 25% → 40% → 50% | 1 秒 | “转了，亮了” |

首先检查供电、实际接口方向和六针线序，避免将运行 LED 当成驱动验证。D1/D2 亮只说明控制器进入运行状态，D5 亮只说明定时结束；它们不能证明电机收到功率。

A710 下，用户在电源板 L-1 测到约 0.8 V，与 3.3 V、25% PWM 的直流平均值相符。电机两端最高只读到约 0.05 V，模块 AIN1/AIN2 又未测出电压。这些读数存在短窗口及万用表平均测量的局限，不足以断定驱动损坏或模块输入完全无信号。已确认测量的是右侧、L 上方的左轮模块。

随后保持最高占空比 25%，仅把 PWM 从 20 kHz 改为 1 kHz。单个高电平从 12.5 µs 增至 250 µs，但电机仍不转，说明仅降频没有解决本次问题。A712 保持 1 kHz，并提高爬升阶段及最高占空比至 50%，对应平台高电平 500 µs，用户确认转动及活动灯亮。测试时限同时缩短至一秒。

这个对照支持此前低占空比下启动激励不足，提高启动占空比是本次有效的实现调整。尚未测量桥输出波形、电流、限流设置、摩擦或负载，不能指定其中某项为唯一根因；也不能认定 50% 是最低启动值。当前控制器不依赖编码器反馈允许启动，因此此前活动灯不亮不会阻止 PWM 输出。

## RTL 的具体实现

公共控制器为 `rtl/acg720_motor_test.v`，A712 包装顶层为 `rtl/acg720_motor_test_start50.v`。板载时钟 Y18 为 50 MHz，不使用 PLL、DDR 或摄像头 IP。A712 设置 `PWM_HZ=1000`、`DUTY_PERCENT=50`、`RUN_MS=1000`；一个 PWM 周期为 50000 个时钟，50% 平台为 25000 个时钟。

启动后的前 50 ms 为 10%，50～100 ms 为 25%，100～200 ms 为 40%，之后为 50%，到约 1000 ms 结束。独立 1 ms 时基控制按键防抖、松键确认和运行时限。没有自动重试或根据编码器缺失继续加大占空比的行为。

每台电机使用 AT8236 A 通道的双 IN 接口。一个方向的输入为 IN1=PWM、IN2=0；停止为两个输入都低，电机滑行。此处桥输出方向尚未映射为整车前进，不套用旧 TB6612 固件的独立 PWM/STBY 接口。

S1 只选择左轮，S2 只选择右轮，同时按下拒绝启动。启动前必须两键稳定松开，按住上电、按住复位释放或按住超过时限不会自动启动或重复。S0 低电平异步清除控制状态并门控物理 PWM 输出，释放经同步及启动延时后重新等待松键。

编码器四路经过两级同步，先建立静态基线，再检测任一 A/B 跳变并锁存到 D3/D4。开始新测试时清除两侧历史活动。该实现没有正交解码、四倍频计数、转速计算或 PID。摄像头复位保持低，独立测试位流暂时替代摄像头 SRAM 程序，摄像头与 DDR 源码保留。

## 编译、审查和复现

在 `code/fpga/acg720-motor-test` 目录执行 `build_start50.tcl`，使用 Gowin V1.9.12、器件 GW5AT-LV60PG484AC1/I0。顶层必须选 `acg720_motor_test_start50`；直接编译公共控制器默认得到 A710 的 20 kHz/25% 参数，不能当作已通过配置。

Icarus 仿真已检查 A710 公共安全逻辑、A711 的 1 kHz/25% 和 A712 的 1 kHz/50%，覆盖单轮选择、准确 PWM、超时、按住不重复和 S0 在高电平期间立即停止。仿真缩短运行参数，实际 A712 编译顶层为一秒。`tests/audit_build.py --variant start50` 对实际 PNR 检查 21 个端口、球号、方向、3.3 V IO、四路驱动下拉及位流 User Code。

50 MHz setup/hold 违反端点均为 0，报告 Fmax=183.823 MHz。首次布线工具异常退出后重新构建成功；失败产物未下载。下载使用 Programmer 的 `operation_index=2`，随后独立读取 User Code 和 Status，均与 A712 记录一致。

通过位流为 `release/A712/acg720_motor_test_start50.fs`，SHA256：

```text
84B3E192B543C1EF72AAC51B141E789BF2733C6563BE163DEAA7D5FE1A0DA7FF
```

源码哈希、实际 PNR 审查、仿真、下载及回读证据放在同目录。逐轮架空测试时，松开 S1/S2，按一次 S1，观察旋转及 D3；等三秒后按一次 S2，观察旋转及 D4。第二次测试会清除第一次活动记录。S0 停止输出；定时结束 D5 亮。

## A712 实现边界

通过的是手动、架空、单轮、短时启动及编码器活动测试。当前最高 50% 是经本次实物验证的参数，尚未验证长时间负载、电流、车身前进方向、速度闭环或摄像头与电机同时运行。

本次只写 SRAM，没有修改外部 Flash，断电后 A712 丢失；重新供电将运行 Flash 原有程序，若要继续该电机测试须重新下载 A712。后续闭环实现应先确认各轮方向及编码器 A/B 计数，再增加速度计算和受限的 PID 输出。

## 用户后续要求的持续运行版 A713

A712 启动通过后，用户要求按 S1/S2 分别让左/右轮持续转动，再按一次停止，并提高速度。A713 使用新文件 `rtl/acg720_motor_toggle.v`，保留 A712 构建快照。按键防抖后检测有效按下事件，每个事件只翻转对应轮的运行位；另一轮状态独立，允许两轮同时运行。每键在配置、S0 或前次事件后必须先稳定松开，长按不会重复翻转。

去除单次超时，以两个独立且饱和于 400 ms 的爬升计数器控制启动占空比。前 200 ms 沿用 10%→25%→40%，200～300 ms 为 50%，300～400 ms 为 60%，之后为 65%。两轮共享 1 kHz 周期计数，分别比较各自占空比。再次按键将对应运行位清零，立即门控为低；S0 直接门控两路 PWM 并异步复位。停止为 IN1=IN2=0 的滑行，不是机械瞬停。

编码器同步和活动基线延续原实现，启动某轮时仅清除该轮活动记录。D1/D2 是左右运行状态，D3/D4 是活动记录；D5 改为两轮都停止，D6 保留且灭，D7 仍为心跳。该实现为开环持续驱动，65% 不等同于已测量的转速；尚未加入转向切换、速度反馈控制、电流测量或摄像头合并。

专用仿真已覆盖配置时按住两键、防抖、准确 65% 周期、持续超过原两秒时限、第二次按下停止、长按不会重启、另一轮继续运行、同时切换两轮、编码器历史独立清除及 S0 在时钟边沿间停止。编译和下载的实际结果另记于工程 README 的 A713 完成记录。

A713 已完成 Gowin 编译、实际 21 个管脚核对和 50 MHz 时序审查，setup/hold 违反端点为 0，Fmax=184.374 MHz。SRAM 下载后独立回读 `0x0000A713`、Status=`0x70022020`，未写 Flash。位流及原始证据放在 `release/A713/`；SHA256 为 `A144E8D407B4D39044E1852272FFC0E007B97EFCCD6E736DA8F3A85F61831307`。用户回复“都可以了，再调快点，调到80%”，确认左右持续启停正常；没有提供量化转速或负载数据。

## 80% 参数版 A714

用户指定 80% 后新增 `rtl/acg720_motor_toggle_80.v` 包装顶层，复用 A713 控制器，只把 `DUTY_PERCENT` 从 65 改为 80。PWM 保持 1 kHz，每周期 50000 个板载时钟，80% 平台为 40000 个时钟；启动前 400 ms 保留 10%→25%→40%→50%→60%，之后保持 80%。按键、S0、编码器及硬件接线均沿用 A713。

使用 `acg720_motor_toggle_80.gprj`、`build_toggle80.tcl` 和 `tests/audit_build.py --variant toggle80`。同一持续运行测试通过宏 `TOGGLE80_TEST` 实例化 80% 包装顶层，验证平台、持续运行、按键启停和 S0。实际构建及下载记录见工程 README 的 A714 完成记录。

A714 编译、引脚和 50 MHz 时序检查通过，Fmax=170.122 MHz；SRAM 下载后独立读取 `0x0000A714`、`0x70022020`。SHA256=`4E65CDF93D7B43819BFF3ACB35E94D34A5DE69E4DF51D26C7BFD1F11E373EC23`，证据保存在 `release/A714/`。用户反馈感觉没有明显变快，并询问频率影响；尚无转速数据，不记录加速已经实现。

## 频率对照 A715

A715 保持 80% 和同一持续启停逻辑，将 PWM 从 1 kHz 改为 20 kHz。AT8236 原厂手册允许至 100 kHz 输入，本次 20 kHz 在其范围内。原先 A710 的 20 kHz/25% 不能启动，与现在 20 kHz/80% 的对照条件不同，不能据此前结果预判 A715。

当前 IN1=PWM、IN2=0 是快衰减方式。频率和衰减会改变绕组电流建立及关断过程，但调整频率不能直接按比例提升转速，80% 占空比也不等于电机达到额定转速的 80%。VREF/检流电阻可能限制电流，VM 可能在负载下变化；这些因素尚未测量，不作为已确认原因。参考来源及构建细节见工程 README 的 A715 节。

仿真以 `TOGGLE20K80_TEST` 实例化 20 kHz/80% 包装顶层，同时统计每毫秒上升沿数和高电平数量，确认实际频率和占空比；保留持续启停、两轮独立及 S0 测试。后续如需判断实际加速，应使用编码器计数得到同一工况下的脉冲率，当前 D3/D4 活动灯不提供该数据。

A715 仿真及编译完成后，用户在下载前要求“直接上50kHz”，因此 A715 没有下载，不记任何实板结果。

## 50 kHz / 80% 版 A716

按照用户指定，新增 `rtl/acg720_motor_toggle_50khz_80.v`，复用 A713 控制器并设置 `PWM_HZ=50000`、`DUTY_PERCENT=80`。周期为 1000 个 50 MHz 时钟，高电平 800 个（16 µs）、低电平 200 个（4 µs），处于 AT8236 手册给出的至 100 kHz 输入范围内。400 ms 爬升、S1/S2 独立持续启停和 S0 停止保持原实现。

`build_toggle50k80.tcl` 编译成功，实际 21 个管脚核对及 50 MHz 时序审查通过，setup/hold 违反端点为 0，Fmax=188.257 MHz。专用仿真在每 1 ms 检查 50 个 PWM 上升沿和 80% 平台，同时验证持续超过原两秒时限、再次按下停止、独立两轮及异步 S0。

下载前读取 A714，SRAM 下载后独立读取 User Code=`0x0000A716`、Status=`0x70022020`。位流和原始证据放在 `release/A716/`；SHA256=`9C85F5250EF1EF790036797F47320E03269E792131773B30437A78106287890B`。只写 SRAM，未写外部 Flash。

该版设置和下载已完成，实际启停、噪声及转速变化仍待反馈；频率变化不能作为提速已实现的证据。当前 D3/D4 为活动锁存，如进一步需要可靠速度比较，应增加编码器脉冲率采样。原有 1 kHz 位流保留供恢复及对照。

## 按键控制占空比循环 A717

用户在 A716 下载后改为要求从最低到最高占空比循环，并保留按一次开始、再按一次停止。A717 使用独立顶层 `rtl/acg720_motor_sweep.v`，保持 50 kHz，默认 `STEP_PERCENT=5`、`STEP_MS=500`。左右各自保存循环开启位、当前占空比门限和本档毫秒计数，周期计数器由两轮共享。

50 MHz / 50 kHz 得到每周期 1000 个时钟，每 5% 对应 50 个高电平时钟。某轮有效启动时清零该轮门限及计时，第一档为 0%；每 500 个 1 ms 时基事件增加 50，到 1000 后保持一档，再清零并重复。共 0%、5%、……、100% 的 21 档，一轮约 10.5 秒。新门限在 PWM 周期边界锁存生效，避免中途变更比较值产生不完整脉冲。100% 的比较门限为 1000，计数范围为 0～999，故始终为高；0% 始终为低。该门限使用能表示 1000 的 10 位，加法先保留进位，再截取合法范围，最后增加是 950+50，不会越界。

S1 只切换左轮、S2 只切换右轮，两轮可同时开启且循环进度独立。停止时对应运行位门控物理输出为 0，下一次开启从 0% 开始。沿用稳定松键确认、防抖、长按只触发一次、S0 异步停止及编码器活动采样；启动某轮只清除该轮活动记录。D1/D2 在 0% 档也表示循环开启，D5 表示两轮都停止，D6 在任一轮实际占空比门限达到 100% 时亮。电机仍采用 IN1=PWM、IN2=0，一个桥方向，停止为滑行。

专用仿真保持输出为真实 50 kHz，将测试时钟设为 5 MHz，以每周期 100 个时钟精确表示所有整数百分比。为了加速，将每档改为 4 ms、防抖为 2 ms，逐档统计高电平数量及上升沿。验证左轮两轮完整循环、右轮完整循环及回绕，所有 21 档均匹配，0% 无脉冲、100% 无低电平；另覆盖独立启停、重新从 0% 开始、按住不重复、短暂抖动、另一键保持按下时的启动锁定、编码器历史独立清除以及 S0 在时钟边沿间立即停止。实际编译顶层仍使用 50 MHz、500 ms 和 20 ms。

Gowin V1.9.12 编译和实际 21 个管脚审查通过；50 MHz setup/hold 违反端点均为 0，Fmax=184.331 MHz。下载前读取 `0x0000A716`，operation_index=2 SRAM 下载完成后独立读取 `0x0000A717`、Status=`0x70022020`。位流及原始证据放在 `release/A717/`，SHA256=`B54E13D91CA2C3A3F0A788FA0ACB1AB27E2A2DB854872CBFF902E770F6D48BC7`。复现命令及完整使用方法见工程 README 的 A717 节。

本次未修改 A712～A716 已归档构建所用的 RTL、引脚约束和构建入口，未写外部 Flash。程序和下载检查已完成；低占空比阶段可能暂时不转，机械转速也不会瞬间跟随占空比归零。实物循环、再次按键停止和速度表现待反馈，当前仍是开环占空比扫描，没有速度计算或 PID。

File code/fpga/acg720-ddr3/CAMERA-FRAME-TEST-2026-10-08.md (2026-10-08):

# OV5640 → 官方帧缓存整帧验证

采用已通过的第 38 章 DDR 基线，DDR 参考来自原始板载 50 MHz，400 MHz memory clock / 100 MHz UI；保留系统 PLL 50/165 MHz 及 33 MHz 读 FIFO 时钟。摄像头 PCLK 仅用于官方 DVP_Capture 和写 FIFO，不给 DDR 提供参考时钟。现有 P7 接线未改变。

## 彩条版下载记录

- 工程：`.local/framebuffer-first/ch38-camera-bars/ch38_camera_bars.gprj`
- 编译：`build_ch38_camera_bars.tcl`，综合、布局布线、位流生成完成。
- 位流：`.local/framebuffer-first/ch38-camera-bars/impl/pnr/ch38_camera_bars.fs`
- SHA256：`5C13FEA6833E57650914D20B5983ED79A3BC3F629AAC3DCAD06833C74970BD92`
- SRAM 下载成功；User Code `0x00004FCF`，Status `0x70026020`。
- 下载器 FT2CH / location 8740，15 MHz JTAG。未写外部 Flash。
- 用户确认 D0～D5 亮、D6 灭、D7 闪，摄像头内部彩条的完整帧检查及 DDR 读回 CRC 已通过。原始结果保存为工作副本 `verified-result-20261008.json`。
- 复位 S0 / F15，低有效；摄像头复位 C14。

| 灯 | 本版含义 |
| --- | --- |
| D0 | 系统 PLL 锁定 |
| D1 | DDR PLL 锁定 |
| D2 | DDR 校准完成 |
| D3 | 摄像头初始化：ID 0x5640 和 7 个关键寄存器读回一致 |
| D4 | 48000 个顺序 DDR 写命令完成 |
| D5 | 800×480 完整帧通过检查，384000 个读回像素 CRC 一致，且无其他测试错误 |
| D6 | 摄像头配置、帧尺寸、FIFO 溢出、DDR 命令/响应、超时或 CRC 错误 |
| D7 | 原始板载时钟心跳 |

D0～D5 亮、D6 灭、D7 闪为预期通过状态；与旧摄像头诊断及静态 `0x41A4` 的 D3 定义不同。

## 配置和数据验证

DDR 校准后，摄像头硬复位保持低约 1 ms，释放后等约 20 ms，再以 100 kHz SCCB 配置。采用此前初始化成功的 253 项官方 RGB 表，保留 PLL、裁剪、HTS/VTS、缩放与 DVP 设置，将尺寸参数设为 800×480，`0x503D=0x80` 开启内部彩条。模块振荡器频率尚未测得，不据旧表注释承诺帧率。

写表后读回 ID `0x300A/0x300B`，并核对 `0x3808..0x380B` 的 800×480、`0x4300=0x61`、`0x501F=0x01`、`0x503D=0x80`。只有全部一致才亮 D3。RGB 表常量赋值块在本地副本增加 addr 显式敏感项，避免 Icarus 对常量-only `always @*` 不执行的仿真陷阱；原资料与旧工程未改。

官方 DVP_Capture 在配置完成后复位释放并舍弃前 10 帧。camera_frame_gate 等完整帧边界，逐行检查 800 个有效像素、480 行，共 384000；任何短行、长行或错误边界拒绝通过。

采集端按接受进入写 FIFO 的像素计算 CRC32（反射多项式 0xEDB88320，初值及最终异或均 0xFFFFFFFF，高字节先入）。只写一次完整帧。等待全部写命令被接受及完整帧检查通过，发出 48000 个顺序读命令，按官方 FWFT 读 FIFO 的 pop 当拍计算读回 CRC。采集 CRC 在帧完成前已经冻结，以同步完成标志建立稳定多位数据传递。CRC 一致是整帧传输验证，不等于逐像素色彩/HDMI 显示验证，CRC 本身也存在碰撞可能。

## 已执行检查与限制

- 采用实际官方 DVP_Capture 的仿真，完整 384000 像素通过；CRC 与 Python zlib 独立金值 `0xCC8B28AB` 一致。
- 两行测试覆盖异步时钟、FIFO empty 暂停、读回末像素损坏、短行和写 FIFO 满。错误不能报 pass。
- 配置控制器使用实际 ROM 和事务级 SCCB 模型，确认 253 次写、2 次 ID 读、7 次配置读；坏彩条或尺寸读回不报 init_done。该模型不验证电气 SCCB 时序。
- PNR 中 camera_pclk 使用 PRIMARY；BSRAM 35/118、SSRAM 0，mDRP 适配器保留。
- PCLK 暂按保守 100 MHz（10 ns）约束；报告本域 Fmax 108.954 MHz，读域 52.450 MHz，UI 185.056 MHz。总报告仍有 205 setup、56 hold 违反端点，未完整时序/CDC 签核，未以全局 false path 隐藏。
- 无 HDMI 显示器参与，没有验证连续视频、乒乓缓冲、长期运行或全 DDR 容量。

日志位于 `.local/logs/ch38-camera-bars-build-20261008.log`、`ch38-camera-bars-program-20261008.log`、`ch38-camera-full-sim-20261008.log`、`ch38-camera-ctrl-sim-20261008.log`。静态整帧位流 `0x41A4` 和其源码/哈希单独保留。

## 实景帧继续验证

彩条版通过后，建立独立 `.local/framebuffer-first/ch38-camera-live/ch38_camera_live.gprj`，编译入口 `build_ch38_camera_live.tcl`。相对彩条版只将实际表中的 `0x503D` 从 `0x80` 改为 `0x00`，并将该寄存器读回期望改为 `0x00`；DDR 时钟、FIFO、尺寸、格式、完整帧检查和 CRC 逻辑均保持一致。沿用全部灯态含义，实景结果由对应位流的单独反馈确认。

实景版综合、布局布线和 SRAM 下载已完成。当前板上为：

- 位流：`.local/framebuffer-first/ch38-camera-live/impl/pnr/ch38_camera_live.fs`
- SHA256：`A718EFC364FEB9A6B47AD333686F0518D76A56DAD1955ABBA607262CAE790553`
- User Code / Status：`0x0000AF89` / `0x70026020`
- 用户确认 D0～D5 亮、D6 灭、D7 闪，关闭彩条的实景完整帧检查及 DDR 读回 CRC 通过；S0 可重新触发整帧测试。结果保存为实景工作副本 `verified-result-20261008.json`。
- 两个源码差异已经逐文件核对并保存在 `build-audit-20261008.json`，其余 src 文件字节一致。
- 实景表的配置读回控制器仿真通过；时序报告 206 setup、56 hold 违反端点，仍未完成签核。
- 日志：`.local/logs/ch38-camera-live-build-20261008.log`、`ch38-camera-live-program-20261008.log`、`ch38-camera-live-ctrl-sim-20261008.log`。

当前只缓存并检验一帧，不提供已验证的连续 HDMI 视频。仅 SRAM 下载，断电会丢失当前 FPGA 配置；配置 Flash 未改写。完整实现和复现文档见 [DDR3-FRAMEBUFFER-IMPLEMENTATION-2026-10-08.md](DDR3-FRAMEBUFFER-IMPLEMENTATION-2026-10-08.md)。

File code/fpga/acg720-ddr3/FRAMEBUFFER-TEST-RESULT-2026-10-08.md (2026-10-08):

# 第 38 章整帧 DDR3 验证结果

2026-10-08，用户确认位流 `0x41A4` 的 D0～D5 亮、D6 灭、D7 闪。800×480、RGB565，共 384000 像素 / 768000 字节，经官方写 FIFO → DDR3 → 官方读 FIFO，逐像素比较通过。摄像头在这次测试中保持复位；没有验证摄像头数据或 HDMI 图像。

## 可恢复基线

- 工程：`.local/framebuffer-first/ch38-frame-test/ch38_frame_test.gprj`
- 编译入口：`build_ch38_frame_test.tcl`
- 位流：`.local/framebuffer-first/ch38-frame-test/impl/pnr/ch38_frame_test.fs`
- SHA256：`DD7959D0C266BD507D50DE8FBCF6DE9F9487E5F3B2076F643A168929D81A6222`
- User Code：`0x000041A4`；下载后 Status：`0x70026020`
- 下载器：FT2CH，location 8740，FPGA ID `0x0001481B`；仅 SRAM 下载，未写外部 Flash。
- 复位：S0 / F15，低有效。
- 实板结果原始记录：`.local/framebuffer-first/ch38-frame-test/verified-result-20261008.json`
- 编译与下载日志：`.local/logs/ch38-frame-test-build-20261008.log`、`.local/logs/ch38-frame-test-program-20261008.log`

| 灯 | 0x41A4 的含义 | 用户反馈 |
| --- | --- | --- |
| D0 | 系统 PLL 锁定 | 亮 |
| D1 | DDR PLL 锁定 | 亮 |
| D2 | DDR 校准完成 | 亮 |
| D3 | 收到恰好 384000 个测试像素 | 亮 |
| D4 | 接受 48000 个顺序 DDR 写命令 | 亮 |
| D5 | 恰好 384000 个读 FIFO 像素逐个一致 | 亮 |
| D6 | 溢出、地址/响应错误、超时或比较错误 | 灭 |
| D7 | 原始 50 MHz 时钟心跳 | 闪 |

## 本次修正及证据

1. 保留官方第 38 章时钟拓扑。DDR PLL 使用板载原始 50 MHz 参考，400 MHz memory clock；系统 PLL 输出 50/165 MHz，CLKDIV 输出 33 MHz 用于读 FIFO。UI 为 100 MHz。摄像头 PCLK 不参与 DDR 参考时钟。
2. 根据原厂 [25K/60K DDR 更新说明](https://fpga.cn/forum.php?mod=viewthread&tid=29815)，用 16 拍锁定延迟交出 PLL mDRP 控制权；综合网表中确认适配器保留。旧源码 `pll_init_bypass=0` 的控制连接缺陷已经修正，但未单独做 A/B 实板测试，不能据此认定它是此前所有诊断失败的唯一原因。
3. 第 38 章原生成的两个 FIFO 在本机 Gowin 1.9.12 / 60B 独立综合时报 RP0007，提示当前器件没有 SSRAM。采用资料包第 47 章生成的 FIFO 实现后独立综合、完整综合及布局布线通过。替换前确认 `.ipc`、`fifo_parameter.v`、`fifo_define.v` 逐字节相同：8 KiB、EBR、FWFT、无输出寄存器，写 16→128，读 128→16。配置及哈希见工作副本 `fifo-compatibility.json`。该问题解释本轮编译失败，不是旧板上校准失败的直接证据。
4. 只写一次完整帧，等待全部 DDR 写命令接受后才读。检查 48000 个读写命令的地址序列及响应数量；按 FWFT 语义在 pop 当拍比较 Q。读 FIFO 可暂停，完整比较后停止，避免空读和混入下一帧。

## 验证范围与限制

RTL 仿真覆盖两行的字节回绕、FIFO empty 暂停、最后像素损坏、输入溢出、错误地址、提前读、无请求响应、超时及复位；完整 384000 像素仿真通过。另用实际官方字节数据源和 8→16 拼接模块确认期望序列。

静态图案每行重复，字节值以 256 回绕。这不是全容量 256 MiB、唯一地址图案、长期稳定性或双缓冲验证。摄像头完整帧、实景与 HDMI 显示仍需分别测试。

SDC 已定义板载 50 MHz、读 FIFO 33 MHz、DDR UI 100 MHz 时钟，未创建 CLKDIV 时钟的警告已消除。布局布线仍报告 188 个 setup、98 个 hold 违反端点，涉及跨时钟、私有 PHY 和 HDMI 路径；当前不是完整时序签核。硬件单帧通过不能代替时序和 CDC 审核，也没有用全局 false path 隐藏报告。

原厂参考副本 `official-ch38` 的 278 个非 impl 文件保持逐字节一致。通过的静态工程单独保存；摄像头将使用独立副本，并保持相同 DDR 时钟、FIFO 和调度基线。

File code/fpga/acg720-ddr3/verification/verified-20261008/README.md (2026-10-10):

# DDR3 实景 HDMI 固件与验证资料导入

2026-10-10 将用户提供的 `verified-20261008.zip` 合入本目录，30 个原始文件均保留原字节。它来自另一份摄像头工程交付，包含双帧区 HDMI 实景显示固件及证据，与本仓库的静态/单帧 CRC 自检快照分开保存。

## 文件入口

| 内容 | 文件 |
| --- | --- |
| 原始排查与实现报告 | [FINAL_VALIDATION_AND_PROBLEM_SOLVING_REPORT.md](FINAL_VALIDATION_AND_PROBLEM_SOLVING_REPORT.md) |
| 可下载位流 | [firmware/ddr3_live_hdmi.fs](firmware/ddr3_live_hdmi.fs) |
| 构建输入与验证检查 | [firmware/build-inputs.json](firmware/build-inputs.json)、[firmware/build-validation.json](firmware/build-validation.json) |
| 用户实物反馈 | [hardware-evidence/user-verification.md](hardware-evidence/user-verification.md) |
| HDMI 实景照片 | [hardware-evidence/hdmi_scene.png](hardware-evidence/hdmi_scene.png) |
| 正式时序报告 | [pnr-report/ddr3_live_hdmi_tr_content.html](pnr-report/ddr3_live_hdmi_tr_content.html) |
| 测试与历史 | `tests/`、`git-history/` |
| 原始文件校验清单 | [SHA256SUMS](SHA256SUMS) |
| 本次导入的完整校验记录 | [IMPORT-MANIFEST.json](IMPORT-MANIFEST.json) |

位流目标为 GW5AT-LV60PG484AC1/I0 / GW5AT-60B，文件头 User Code=`0x0000BC6C`。SHA256 为 `b6e3967afc4785ff42cb147c1060a8a3d5e2ad39c560904a4f1e8b8b3d8fd6f8`，与包内构建记录及校验清单一致。

## 证据范围

包内用户记录确认 HDMI 实景画面可显示、D6 灭、D7 闪烁。记录同时明确未单独确认镜头移动后的连续刷新、长时间稳定性、配置 Flash 固化及断电冷启动；位流和该次实物反馈的关联来自交付记录，未通过板上配置哈希读回验证。这里归档的是历史证据。

正式 PNR 报告摘要仍有 **101 个 setup、29 个 hold 违反端点**，与 `build-validation.json` 一致，完整时序尚未闭合。构建 JSON 中 `hardware_verified=false` 是编译时状态，后续实物反馈另在 `hardware-evidence/` 记录，原文件均未改写。

包内提供构建源码哈希、脚本哈希及原工程提交摘要，**没有包含完整 RTL、构建脚本或原工程 Git 对象**。本次归档不等于已将那份工程的可编辑源码合并，也无法仅凭该压缩包重新编译同一位流。原报告里的 Linux 路径保留作来源记录，不作为当前 Windows 本机路径。

## 校验处理

ZIP CRC 检查通过。原始 `SHA256SUMS` 的 29 项全部匹配，唯一未列出的是该校验清单本身。原始 `MANIFEST.json` 的其他 28 项匹配，但其中 `SHA256SUMS` 条目仍记录较早的 160 字节版本；包内实际文件为 2893 字节。这属于原始清单的过期记录，保留原件，并在新增 `IMPORT-MANIFEST.json` 中记录全部 30 个实际文件的大小和哈希、压缩包哈希及这一差异。

本目录的 Git 属性关闭文本换行转换，保证推送后的原始资料和位流字节与压缩包一致。

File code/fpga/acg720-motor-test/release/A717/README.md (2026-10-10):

# A717 50 kHz / 0%～100% 循环构建及下载快照

2026-10-10 按用户要求建立独立占空比循环控制器。50 kHz，0%、5%、……、100% 每档 500 ms，约 10.5 秒后回到 0% 重复。S1/S2 独立开启、停止左/右轮循环，重新开始从 0%；S0 停止两轮。默认停止，长按不会重复，无自动超时。

仿真保持真实 50 kHz，缩短每档及防抖时间，逐档检查高电平与上升沿数，覆盖两轮的全范围及回绕、0% 和 100% 端点、独立启停、重新从零开始、编码器历史及异步 S0。实际编译顶层为 50 MHz、每档 500 ms、防抖 20 ms。21 个实际管脚和 50 MHz 时序审查通过，setup/hold 违反为 0，Fmax=184.331 MHz。

SRAM 下载后独立读取 User Code=`0x0000A717`、Status=`0x70022020`。实物循环、再次按键停止和转速表现待用户观察。D1/D2 在循环的 0% 阶段仍亮，D6 在任一轮达到 100% 时亮。

位流 `acg720_motor_sweep.fs`，SHA256=`B54E13D91CA2C3A3F0A788FA0ACB1AB27E2A2DB854872CBFF902E770F6D48BC7`。同目录保留正式构建、仿真、实际 PNR/时序、源码哈希及下载/回读记录，Git 不转换其字节。

只写 SRAM，断电后丢失，未写 Flash。使用说明见 [工程 README](../../README.md)，实现见 [排查与实现文档](../../MOTOR-IMPLEMENTATION-2026-10-10.md)。

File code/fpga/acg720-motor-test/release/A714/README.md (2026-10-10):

# A714 1 kHz / 80% 快照

2026-10-10 用户指定 80% 后构建，沿用 A713 的左右独立持续启停、400 ms 爬升和 S0 停止。仿真、21 管脚和 50 MHz 时序检查通过，Fmax=170.122 MHz。SRAM 下载后独立读取 User Code=`0x0000A714`、Status=`0x70022020`，未写 Flash。

用户反馈感觉没有明显变快，并询问频率影响。该反馈不包含量化转速，不能记录提速已实现，也不能断定实际转速完全没有变化。

位流 `acg720_motor_toggle_80.fs`，SHA256=`4E65CDF93D7B43819BFF3ACB35E94D34A5DE69E4DF51D26C7BFD1F11E373EC23`。同目录保留构建、仿真、实际 PNR/时序、审查及下载/回读证据；Git 保留原始字节。操作步骤见 [工程 README](../../README.md)。

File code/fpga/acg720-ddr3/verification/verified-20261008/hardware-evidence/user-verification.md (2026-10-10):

# DDR3 实景 HDMI 实板功能反馈

日期：2026-10-08（Asia/Shanghai）。

用户反馈：“验证通过 … d6灭 d7闪烁 hdmi能显示画面”。
附图可见 HDMI 显示器上的实景图像。LED 灯态依据用户描述记录，照片不能证明 D7 的动态闪烁。

本次可确认：用户上板后的 HDMI 实景显示功能通过，D6 错误灯灭、D7 心跳闪烁。
未单独确认：D0～D5 的完整灯态、镜头移动后的连续刷新、长时间稳定性、Flash 固化和断电冷启动。

关联交付位流：build/ddr3_live_hdmi/release-2026-10-08/ddr3_live_hdmi.fs。
交付 SHA256：b6e3967afc4785ff42cb147c1060a8a3d5e2ad39c560904a4f1e8b8b3d8fd6f8。
上述位流关联来自本次对话，尚未读回实板配置验证其哈希。

原始编译报告及交付包保持不变；编译时 hardware_verified=false 是当时的状态，本记录补充之后的用户实板反馈。
时序报告仍有 101 个 setup、29 个 hold 违反端点，功能通过不等于完整时序签核。
没有执行任何 SRAM 下载或配置 Flash 擦写。

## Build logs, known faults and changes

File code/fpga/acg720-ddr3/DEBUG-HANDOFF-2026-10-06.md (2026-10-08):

# ACG720 OV5640 -> DDR3 调试交接记录

日期：2026-10-06（Asia/Shanghai，22:41 后停止调试）  
项目：EdgeMind-Robot / code/fpga/acg720-ddr3  
硬件：小梅哥 ACG720，GW5AT-60B，GW5AT-LV60PG484AC1/I0，B 版本  
工具：Gowin V1.9.12_x64，Programmer CLI；USB location 546；SRAM 下载，未写外部 Flash

## 当前板卡状态

最后一次下载的是 B21 复位约束的摄像头 DDR FIFO 诊断位流：

- 文件：.local/camera-ddr/impl/pnr/camera_ddr_fifo_bist_b21.fs
- SHA256：27F08F7004201D8818FBA2226A582EDEC4D1BD0B80FBBE849BB9CC57C08866C9
- 下载方式：programmer_cli.exe operation_index=2，100% 完成
- User Code：0x0000BAE9
- Status：0x70026020
- 用户观察：D0 亮，D1/D2/D3 全灭

板卡当前不是已知通过的主工程，而是失败的临时诊断工程。收到用户停止要求后没有再次编译或下载，只整理文档；整理时没有运行中的 gw_sh/GowinSynthesis/programmer_cli。断电会丢失 SRAM 临时配置，重新上电可能加载外部 Flash 中原有程序，不能沿用本记录的 LED 解释。

明天如需恢复工作状态，应重新下载 .local/ch47/impl/pnr/ov5640_ddr3_hdmi.fs；仍然只使用 SRAM。交接期间曾先恢复该主工程位流，下载成功，但没有收到该次恢复的灯态确认就又换成诊断版；“主工程全亮”是此前用户明确反馈的结果。

## 已确认通过的结果

### 1. JTAG / 器件识别

- 下载器：Gowin USB Cable(FT2CH)
- FPGA ID：0x0001481B
- Programmer 可稳定完成 SRAM Program
- 外部 Flash 没有被本次操作改写

### 2. 独立 DDR3 固定模式 BIST

工程：.local/bist/

- 位流：.local/bist/impl/pnr/ddr3_bist.fs
- 本机综合、布局布线、位流生成成功
- 最终通过版本 SHA256：E3A7E06628D7E7600527DE1F8512C7F75EABC1F56067D59ECA29C410E99C5CBD
- SRAM User Code：0x00007CCF
- 板上结果：D0 亮、D1 亮、D2 亮、D3 灭
- 含义：DDR PLL 锁定、DDR3 校准完成、16 个 128-bit 固定模式突发全部读回一致、无失败

这已经证明 ACG720 板上的 DDR3 PHY、引脚约束和固定模式读写通路可工作。它不等价于完整摄像头帧缓存验证，但足以排除“DDR 芯片必然损坏”。

测试范围：地址 0、8、16、…、120，每次 128 bit，共 256 字节。模式为四组 A5A5A5A5/5A5A5A5A/C3C3C3C3/3C3C3C3C 与地址异或；先全部写入，再全部读回比较，并设置读回超时。未测试全容量、长时间压力或整帧数据。

初版 BIST 使用原始 clk50M 作为 DDR IP 的 clk 参考输入，只亮 D0；改成 camera_pll.clkout2 的 loc_clk50m 后 D0/D1/D2 亮、D3 灭。DDR IP 的用户逻辑仍使用其 clk_out，不可把参考 clk 输入当作 UI 时钟。

### 3. 主 OV5640 -> DDR3 -> HDMI 工程

工程：.local/ch47/ov5640_ddr3_hdmi.gprj

- 位流：.local/ch47/impl/pnr/ov5640_ddr3_hdmi.fs
- 当前保留位流 SHA256：D3CD6E1D3967B70441F22201E6A95FC143C7A99BDF63DE3F3B619E04EB23E09D
- 最近一次直接下载 User Code：0x0000D80B
- Status：0x70026020
- 板上曾观察到：D0/D1/D2/D3 全亮
- 主工程 LED：D0=DDR PLL lock，D1=DDR3 校准完成，D2=OV5640 SCCB 初始化完成，D3=摄像头/HDMI PLL lock

主工程曾同时显示 DDR 校准完成和摄像头初始化完成。HDMI 未接显示器，尚未证明画面内容。

## 失败的摄像头 DDR 诊断

### 原生 DDR 接口诊断

工程：.local/camera-ddr/camera_ddr_capture_bist.gprj

功能：等待 OV5640 初始化，抓取 16 个真实 RGB565 像素，写入 2 个 128-bit DDR burst，再读回比较。

- 综合、布局布线、位流生成成功
- 位流曾下载成功，User Code 0x000065D6
- F15 复位约束版本：D0 亮，D1/D2/D3 灭
- 曾测试 F15/B21 复位方向，不能把现象单独归因于复位按键

保留在磁盘的原生接口诊断是后续 F15 重编版本，SHA256 为 98D589900E7A6BDC80D6A23FAE96110DF18F034BD6FDAC69E3DEC1C160EA4E6A；早期 camera-ddr-capture-bist-20261006.log 中的 46226A... / 0x000065D6 对应初版，不能与当前文件视为同一构建。

### 原厂 DDR FIFO 包装器诊断

工程：.local/camera-ddr/camera_ddr_fifo_bist.gprj

功能：抓取 16 个真实像素，经过原厂 ddr3_ctrl_2port 的写 FIFO、DDR3、读 FIFO，再逐像素比较。

- F15 版本位流 SHA256：59260DB7E4746C3AE221E62B0014CEC3332B70A72C2B30869F8D9C46E18E29D5
- 综合、布局布线、位流生成成功
- 下载成功
- 用户观察：只有 D0 亮
- SRAM User Code：0x0000FC3C；Status：0x70026020

为验证主工程的复位约束，又生成了 B21 版本：

- 工程：.local/camera-ddr/camera_ddr_fifo_bist_b21.gprj
- 位流 SHA256：27F08F7004201D8818FBA2226A582EDEC4D1BD0B80FBBE849BB9CC57C08866C9
- User Code：0x0000BAE9
- 下载成功
- 用户观察：仍只有 D0 亮

结论：把 F15 改为 B21 没有解决 D1 不亮；当前失败诊断不能继续作为 DDR 硬件结论。

### 各位流的 LED 含义

| 位流 | D0 | D1 | D2 | D3 |
| --- | --- | --- | --- | --- |
| 主工程 | DDR PLL 锁定 | DDR 校准完成 | 摄像头 SCCB 初始化完成 | camera/HDMI PLL 锁定 |
| 独立固定模式 BIST | DDR PLL 锁定 | DDR 校准完成 | 固定模式读回通过 | 测试失败 |
| 摄像头原生/FIFO 诊断 | DDR PLL 锁定 | DDR 校准完成 | 摄像头初始化且捕获事件已接收 | 像素读回通过 |

后两类诊断的 D3 含义相反。摄像头诊断 D2/D3 灭不能判断 SCCB 本身是否失败，也不能判断测试是否数据不一致，因为 DDR 校准没完成时状态机还没进入这些阶段。JTAG Status/User Code 仅证明配置身份和下载状态，不包含 DDR 运行结果。

## 摄像头映射与初始化

当前工作副本使用 C:/Users/sc/Downloads/cam 实测映射：

- RST C14，SCL B13，SDA D15
- PCLK B18，HREF D14，VSYNC C13
- D0..D7：C15/B15/B16/D17/C17/E16/D16/B17
- 摄像头模块自带 25 MHz 振荡器；FPGA 不再输出 XCLK
- PWDN 未引出，必须在摄像头模块端固定低电平或有可靠下拉
- SCCB 已改为 100 kHz 开漏双向；读取 0x300A=0x56、0x300B=0x40

主工程上板 D2 曾亮，说明 SCCB 初始化链路已经通过；失败诊断中 D2 还包含“抓到 16 个像素”，不能把 D2 灭简单解释为 SCCB 失败。

工作副本移植了 cam/rtl/ov5640_ctrl.v 与 sccb_master.v，并与第 47 章 RGB 初始化表结合；主工程将摄像头复位保持约 1 ms，释放后等待约 20 ms 才启动 SCCB，初始化完成包含 0x5640 ID 检查。DVP_Capture 丢弃前 10 帧，不能以刚下载时瞬间 D2 灭判定无像素。

复位输入：原厂工程/通过的独立 BIST 使用 F15；当前主工程使用 B21，历史 cam 记录标为 S4。不能写成“S0/B21”。B21 诊断 CST 保留了拷贝自 F15 文件的 S0 注释，该注释过时，以实际 IO_LOC 为准。前一条进度消息把 F15/B21 说成旧版与当前版区别，没有板卡版本证据，撤回该说法；已证实的只有不同工程选择了不同输入球号、切换后诊断仍失败。

此前使用过 M20/B2/B1/J2/L18/A1 等旧摄像头映射，主工程 D0/D1/D3 亮、D2 灭；重新接线后仍未初始化。用户随后提供 Downloads/cam，核对并切换到上述 C14/B13/D15/B18 等映射及 SCCB 控制器后，主工程四灯全亮。旧映射只作历史参考。

PWDN：用户曾表示需要断电确认、随后重新接好线；没有单独的电气测量记录，因此不可声称已测量确认其电平。

## 编译与工具证据

所有上述工程均可在许可证恢复后完成 Gowin 综合、布局布线和位流生成。重复出现的警告：

- NL0002：pll_mDRP_intf 被优化器 swept；独立 BIST 和主工程也出现过，暂未证明是根因
- EX3628/EX2830/EX3671：原厂 DDR wrapper/FIFO 重复声明或隐式声明
- EX3791：FIFO 地址表达式 29 bit 截断到 28 bit
- EX3670：burst 实际连接 32 bit 常量到 1 bit 端口
- TA1132：camera_pclk 被识别为时钟但未创建时钟约束；DDR PHY 内部生成时钟也有同类提示

这些警告应在继续工作时清理，但目前不是已证明的板上故障根因。

工具实际路径：

- 综合/P&R：C:/Gowin/Gowin_V1.9.12_x64/IDE/bin/gw_sh.exe
- 下载：C:/Gowin/Gowin_V1.9.12_x64/Programmer/bin/programmer_cli.exe
- 用户最初提供的 V1.9.12.04_x64 路径本轮未找到 gw_sh.exe；以成功运行的 V1.9.12_x64 路径为准。
- 本地 build*.tcl 设置 use_sspi_as_gpio=1，以释放板上使用的复用 GPIO。
- 许可证已能支持成功编译；不应再重跑早期 MAC/临时网卡脚本，也不需要教育版。

PNR 报告显示主工程使用 6 个 PRIMARY、2 个 CLKDIV，FIFO 诊断使用 4 个 PRIMARY、1 个 CLKDIV；loc_clk50m 在主工程与诊断中的时钟树覆盖也不同。camera_pclk/B18 实际被布到 PRIMARY，因此 TA1132 应解释为缺少时钟创建/时序覆盖，不能直接说它一定用了普通布线。

无独立 SDC 的工程生成位流不等价于完整时序签核。本轮尚未完成对所有时钟、CDC、输入延时及 DDR 板级时序的签核。

## 目前最可靠的判断

1. 编译成功：主工程、独立 BIST、两个摄像头 DDR 诊断均成功生成位流。
2. 下载成功：JTAG/SRAM 下载稳定，器件 ID 正确，未写 Flash。
3. DDR 校准成功：独立固定模式 BIST D1 亮；主工程曾 D1 亮。
4. DDR 固定模式数据验证成功：独立 BIST D2 亮、D3 灭。
5. 摄像头像素经 DDR 写入/读回验证：尚未成功；原生接口和 FIFO 包装器两个诊断均停在 D0 亮。

DDR 诊断校准失败的根因尚未定位。下一轮应优先核对诊断顶层与主工程的 DDR PHY/PLL/时钟资源和启动复位差异；这只是排查方向，尚无波形证据证明其中哪一项导致失败。主工程保留了完整 HDMI/CLKDIV/摄像头 PLL 输出连接，失败诊断为了去掉 HDMI 改动了顶层时钟资源和 FIFO 时钟结构。下一轮可在已知 D1 通过的主顶层内增量加入诊断标志。

### 尚未上板验证的诊断代码问题

暂停前阅读源码发现以下风险，未修改、未编译修复版，不能把它们当作 D1 灭的已确认原因：

- FIFO 诊断只投喂 16 个 16-bit 像素，即 2 个 128-bit FIFO word，但 wr_bust_len=8，适配器条件为 wfifo_rcount >= wr_bust_len，因此校准即使通过也可能永远凑不够写入门槛。
- 该诊断地址范围 0..24 与一次 8 burst 请求不匹配；读 FIFO 会在写前预取，仍需确认清 FIFO、等待写完成及读取排程。
- 两个摄像头诊断同步一次 cap_toggle 脉冲，只在 ST_WAIT_CAP 消费事件；若摄像头捕获先于 DDR 校准完成，事件可能丢失，需改成保持完成标志或握手。
- FIFO 检查用延迟一拍的 rd_fire_d 同时持续读，不匹配/停止时仍可能有在途读；必须核对生成 FIFO 的输出模式/延迟及索引语义。
- 摄像头诊断没有完整地将读回失败、等待超时与校准失败分开显示；D3 灭不能区分这些情况。

DDR 参数依据现有说明/工作副本：MT41K128M16JT-125:K，x16，256 MiB，memory_clk 400 MHz，1:4，128-bit UI，BL8，SSTL 1.5 V。主工程 1280×720 RGB565，一帧 1,843,200 字节；读写同一地址范围，尚无独立多帧乒乓管理。

## 历史记录与证据范围

已参考用户指定的 Downloads/FPGA OV5640 Camera Interface and Verilog Capture Development (1).md 和 Downloads/cam。历史文件中的“不要移植第 47 章”“60K 必须重生成所有 IP”等是当时工作指令/判断，不替代本次用户授权；本次成功编译和 BIST 上板读回已证明当前所用 IP 至少可在现有环境工作。CST 文件头仍写 138K，但实际项目 XML/编译目标为 GW5AT-60B，不能仅凭注释认定器件不匹配。

旧 README 曾同时写“编译成功”和“许可证失败、没有本机位流”，并把未通过的摄像头像素测试描述成验证结果；本次整理已纠正。早期日志保留原样，有 pending、旧映射、旧位流哈希/旧 User Code 等信息，阅读时必须按对应构建区分。

原厂资料位于 C:/Users/sc/Documents/Dev/Hardware/fpga/小梅哥ACG720国产高云FPGA教学开发板资料/02_例程源码/GW5AT60K/第47章 OV5640摄像头采集HDMI显示屏显示；工作修改仅在 code/fpga/acg720-ddr3 内。原厂源码/IP/位流/日志放在被 .gitignore 忽略的 .local 下，许可证不写入本文。没有提交、推送或改动无关 PCB 文件。

## 明天的建议起点

1. 先下载主工程位流 ov5640_ddr3_hdmi.fs，确认 D0/D1/D2/D3 全亮。
2. 保留主工程的 DDR PLL、camera PLL、CLKDIV、DDR wrapper、复位和约束不动。
3. 只在主顶层加入粘滞状态位：DVP DataValid 见到、写 FIFO 入数增加、读 FIFO 出数增加；先不改变 DDR 物理接口。
4. 再加入有限窗口的写入/读回比较，并分别给出“捕获到像素”“DDR 命令发出”“读回一致”三个独立 LED 状态。
5. 再决定是否修复独立诊断：先处理写入门槛、地址范围、捕获事件保持及超时显示，再核对校准。
6. 清理重复声明、隐式网线、地址位宽截断，并补充 50 MHz、camera_pclk、PLL/DDR UI 时钟约束；分步验证，避免同时改变过多变量。

## 恢复命令（仅供明天续调，本次未执行）

先重新扫描下载器，USB location=546 只是今天记录。确认后，在 code/fpga/acg720-ddr3 目录使用以下 PowerShell 命令恢复已知主工程：

    $acg720Fs = (Resolve-Path .local/ch47/impl/pnr/ov5640_ddr3_hdmi.fs).Path
    & 'C:/Gowin/Gowin_V1.9.12_x64/Programmer/bin/programmer_cli.exe' --device GW5AT-60B --operation_index 2 --fsFile $acg720Fs --cable-index 1 --location 546 --frequency 15MHz

编译主工程：

    & 'C:/Gowin/Gowin_V1.9.12_x64/IDE/bin/gw_sh.exe' ./build.tcl

恢复前不要覆盖当前通过版本的位流及其报告，保留 SHA256 以便准确比较。

## 相关文件

- README.md
- build.tcl
- build_camera_ddr_bist.tcl
- build_camera_ddr_fifo_bist.tcl
- build_camera_ddr_fifo_bist_b21.tcl
- .local/ch47/ov5640_ddr3_hdmi.gprj
- .local/bist/ddr3_bist.gprj
- .local/camera-ddr/camera_ddr_capture_bist.gprj
- .local/camera-ddr/camera_ddr_fifo_bist_b21.gprj
- .local/logs/ddr3-bist-program-20261006.log

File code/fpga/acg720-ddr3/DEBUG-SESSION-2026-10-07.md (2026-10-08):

# ACG720 DDR3 续调（2026-10-07）

## 基线复核

继续用户 10 月 6 日交接，许可证已解决；不再改 MAC/网卡或安装教育版。仅 SRAM 下载，未写外部 Flash。

- JTAG：FT2CH，location 546，器件 ID 0x0001481B。
- 已核对主工程与固定模式 BIST 的 SHA256，均与交接一致。
- 恢复 `.local/ch47/impl/pnr/ov5640_ddr3_hdmi.fs`，User Code `0x0000D80B`，Status `0x70026020`。
- 用户再次明确反馈：D0/D1/D2/D3 全亮。当前接线下 DDR 校准和 OV5640 初始化可通过。
- 恢复日志：`.local/logs/restore-main-20261007.log`。

## 保留主工程结构的被动观测版

工程 `.local/main-observe/main_observe.gprj`；入口 `build_main_observe.tcl`。从已知主工程复制源码，原主工程及通过的 BIST 位流均未覆盖。

只增加状态寄存器及 LED4..7 输出；原 camera PLL、DDR PLL、CLKDIV、DDR/FIFO 控制、复位、HDMI 和摄像头引脚连接保持原有逻辑。增加探针后布局会变化，不能认为物理布局完全不变。

| 灯 | 含义 |
| --- | --- |
| D0 | DDR PLL 锁定（实时） |
| D1 | DDR 校准完成（实时） |
| D2 | OV5640 初始化完成（实时） |
| D3 | camera/HDMI PLL 锁定（实时） |
| D4 | DVP DataValid 曾有效，摄像头复位清除 |
| D5 | 写 FIFO 在非复位、非满时曾接收写使能，系统复位清除 |
| D6 | DDR 原生写命令及写数据曾同时握手，系统/UI 复位清除 |
| D7 | D6 置位后曾出现 DDR rd_data_valid，系统/UI 复位清除 |

D4..7 是粘滞活动标志，不表示连续无丢数或数据比较通过。D7 不保证返回的地址就是先前写入的地址。

LED4..7 球号 K22/J22/H22/M21 已从资料包原厂管脚表核对。

本机综合、布局布线及位流生成成功，6 个 PRIMARY、2 个 CLKDIV、2 个 PLLA，与主工程资源数量相同。仍存在历史未创建时钟、重复声明等警告，尚未完成完整时序签核。

- 位流：`.local/main-observe/impl/pnr/main_observe.fs`
- SHA256：`5ECFAC90A00CA053CF01F9E78769D46AED892E8C9372848AE5232526E5CBE863`
- SRAM 下载成功，User Code `0x00007E20`，Status `0x70026020`。
- 用户 LED 反馈：D1 不亮；补充确认 D0/D2/D3/D4/D5 都亮。D6/D7 未单独明确反馈。
- 编译日志：`.local/logs/main-observe-build-20261007.log`
- 下载日志：`.local/logs/main-observe-program-20261007.log`
- 源码改动：`.local/main-observe/passive-probes.patch`
- 基线源码/位流指纹：`.local/main-observe/baseline-sha256.json`

## PLL mDRP 控制权缺陷与修正实验

观测版保留了原时钟拓扑仍未校准，但 D0/D3 锁定，D2 摄像头初始化、D4 像素、D5 FIFO 输入均有活动。尚不能由此证明布局布线本身是根因。

查到可以直接由源码证明的缺陷：主顶层把 DDR PLL 的 `pll_init_bypass` 固定为 0；`pll_init.v` 第 388..391 行仅在 bypass=1 时把外部 MDOPC/MDAINC/MDWDI 和 MDRDO 接通。因此 DDR `pll_stop` 的适配器虽然例化，却被隔离并综合删除。此前通过版本也有这个缺陷，曾经通过不代表该控制路径正确；不能据此断言每次失败都由这一项引起。

依据：[高云 UG306 的 PLL mDRP 控制权和切换流程](https://cdn.gowinsemi.com.cn/UG306.pdf)，以及[芯路恒/小梅哥管理员 2025-10-17 针对 25K、60K 的更新方法](https://fpga.cn/forum.php?mod=viewthread&tid=29815)。DDR 的 `pll_stop` 必须能控制 memory_clk；高云 DDR3 IP 指南第 4.4.4 节另有说明。

在独立副本 `.local/main-mdrp/` 中，仅将原两级 lock 延迟改为 16 级，将其末级接 `pll_init_bypass`、适配器 pll_lock 与 wr 的使能条件。延迟寄存器额外提供零初值及外部复位，其他 PLL/IP 实现不变。入口 `build_main_mdrp.tcl`，差异 `.local/main-mdrp/mdrp-handoff.patch`。

- 综合、P&R、位流生成完成；网表保留 `pll_mDRP_intf u_pll_mDRP_intf`，之前的 NL0002 删除警告消失。
- 位流 `.local/main-mdrp/impl/pnr/main_mdrp.fs`
- SHA256 `A95113AE7721BD6BB3076DE045E29DE152222B561802D66D55A824AA45D9E07C`
- SRAM 下载完成，User Code `0x00002D41`，Status `0x70026020`。
- LED 定义与观测版一致；用户结果待确认。
- 日志 `.local/logs/main-mdrp-build-20261007.log`、`.local/logs/main-mdrp-program-20261007.log`。

## 读回比较器准备

`rtl/ddr_readback_monitor.v` 为独立的被动监视模块，暂未接入或下载。依次观察地址 0、8、…、120 的 16 个 128-bit 块；记录目标读命令之前最近一次握手成功的写数据，按全部读命令/响应的序号匹配返回值。只有 16 个地址均比较通过才置 pass；数据不一致或已发出的目标读命令超时置 fail。等待目标写/读命令期间不记超时，pass 后停止。样本可来自不同帧，不是整帧比对。

从 [Icarus Windows 发行页面](https://www.bleyer.org/icarus/) 下载成品安装器，在 `.local/tools/iverilog/` 安装；实际版本 12.0 (devel)，不是最新稳定版本。未自行实现仿真工具。安装器 SHA256 `A614057374DFAED5DA0FE454CDEB410E54981FD85DBD28BD472F4CCB765DEB84` 仅作身份记录。

`tests/ddr_readback_monitor_tb.v` 仿真已通过：无写入的预取、握手未接受、写覆盖、读响应顺序、同时发命令和回数据、16 地址完成、错误注入、无返回超时、UI 复位及序号回绕。日志 `.local/logs/ddr-readback-monitor-sim-20261007.log`。此仿真验证比较器自身，不模拟加密 DDR PHY，不代表实板像素读回已通过。

## 尚待完成

先根据八灯判断活动链路，再进行地址可对应的真实像素读回比较。旧独立诊断的校准失败原因仍未证实；FIFO 诊断只写 2 个 128-bit 块却设 8 块门槛、捕获事件可能丢失等代码缺陷仍保留作历史证据。

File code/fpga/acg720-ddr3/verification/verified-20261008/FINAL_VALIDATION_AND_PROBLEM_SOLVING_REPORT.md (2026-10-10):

# ACG720 摄像头实景 → DDR3 帧缓存 → HDMI 连续显示验证交付报告

**报告日期：2026-10-08（Asia/Shanghai）**  
**交付目录：** `/home/tinsiag/Documents/cam/build/ddr3_live_hdmi/verified-20261008`  
**目标器件：** GW5AT-60B / GW5AT-LV60PG484AC1/I0  以及 ACG720 开发板

## 1. 最终验证结论

本目录保存的是已经编译完成、并由用户在实板上验证显示功能的固件：

- HDMI 显示器能够显示 OV5640 摄像头实景画面；
- D6 熄灭，未观察到固件错误指示；
- D7 闪烁，系统心跳正常；
- 摄像头 → DDR3 帧缓存 → HDMI 连续显示链路在本次实板条件下验证通过。

因此，本目录中的 `firmware/ddr3_live_hdmi.fs` 是**实板功能验证通过的 SRAM 下载位流**。它不是只通过仿真的文件，也不是单帧 CRC 自检固件。

位流 SHA256：`b6e3967afc4785ff42cb147c1060a8a3d5e2ad39c560904a4f1e8b8b3d8fd6f8`

照片证据见 `hardware-evidence/hdmi_scene.png`，用户反馈原文见 `hardware-evidence/user-verification.md`。

## 2. 需求、问题与解决路径

### 2.1 原始目标

原始需求是把 TY-OV5640 摄像头实景经过 DDR3 帧缓存后，持续输出到 HDMI 显示器，而不是采集一帧后停止。

### 2.2 早期问题：旧诊断只亮 D0

历史记录显示，旧 DDR/摄像头诊断只亮 D0。不能据此直接判断 DDR 芯片损坏，因为旧流程在 DDR 校准完成前就没有继续推进。源码审查还发现：

1. 旧诊断只产生 16 个 RGB565 像素，即 2 个 128-bit 数据块；适配器的 `wr_bust_len=8` 要求至少 8 个块，写入启动门槛达不到。
2. 状态机用固定延时进入读阶段，没有等待 DDR 实际写命令完成。
3. 读 FIFO 为 FWFT，队首 Q 在 pop 当拍有效；旧代码延迟一拍比较，连续读时可能与下一个像素错位。
4. 一次性 toggle 事件可能在校准等待期间到达而被错过。

**解决方向：** 不再用小样本、固定延时和错位比较判断整条链路，改用完整帧、实际握手和明确的跨时钟状态保持。

### 2.3 第 38 章工程综合失败

官方第 38 章的生成 `rd_data_fifo.v`、`wr_data_fifo.v` 在 GW5AT-60B 当前 Gowin 版本下触发 `RP0007`，提示当前器件没有 SSRAM 资源。

**解决办法：** 采用资料包第 47 章中可在本器件上综合的 BSRAM FIFO 实现，并逐项核对 `.ipc` 配置。最终保持：

- 写 FIFO：16 bit → 128 bit，8 KiB，FWFT，非输出寄存；
- 读 FIFO：128 bit → 16 bit，8 KiB，FWFT，非输出寄存；
- 生成 FIFO 配置与参考配置匹配；
- 最终报告确认 SSRAM=0，BSRAM 使用 38/118。

### 2.4 DDR PLL 与时钟路径

采用第 38 章的 DDR3 基线：原始 50 MHz 作为参考，DDR memory clock 400 MHz，DDR 用户接口 100 MHz；系统 PLL 提供 50 MHz、165 MHz，CLKDIV 产生 33 MHz HDMI 像素时钟。

根据历史记录修正 DDR PLL mDRP 交接：PLL 锁定后等待 16 拍，再通过原始 50 MHz 域登记 `pll_stop` 边沿并交出 mDRP 控制，避免初始化控制被优化或过早交接。

### 2.5 摄像头初始化与整帧捕获

沿用官方 RGB565 初始化表，并使用 800×480 配置：`5001=A3` 启用 scaler、`503D=00` 关闭内部测试、追加 `4741=00` 关闭 DVP 测试。摄像头 ID、格式、尺寸和测试开关进行读回检查。

采集端启动时跳过前 10 帧，之后逐行检查：800 像素、480 行、384000 个 RGB565 像素。短行、长行、奇数字节、额外行、VS 边界异常和 FIFO 满均不发布为有效帧。

### 2.6 连续 HDMI 显示

新增双 DDR 帧区管理：一块只写、一块只读显示。完整帧写完并确认 DDR 命令/数据握手后，等待 HDMI 帧间空白，停止旧读事务、等待旧读返回、清空读 FIFO，再切换显示区。没有新帧时重复上一帧，避免显示撕裂。

仿真已覆盖：完整 800×480 帧、跨时钟 FIFO、DDR 命令/数据独立停顿、帧切换、坏帧丢弃、欠载恢复和显示区保护。

## 3. 编译和测试证据

最终编译目录为：`build/ddr3_live_hdmi/20261008T202857`。Gowin 综合、布局布线、位流生成返回 0，无 ERROR；完整结果见 `firmware/build-result.json` 和 `pnr-report/`。

仿真日志位于 `tests/`，包括：

- FIFO/帧区切换保护；
- 短行、长行、奇数字节、额外行、溢出和 VS 边界检查；
- HDMI 欠载和下一帧恢复；
- 完整管线多帧显示；
- 800×480 摄像头配置事务和读回门控。

Git 关键提交及历史摘要位于 `git-history/`：

- `a1c4aa2`：新增 DDR3 双帧连续 HDMI 固件与实板反馈；
- `052e0f1`：分类 DDR3 live 时序违反；
- `b5fbaf5`：记录时序闭合实验。

## 4. P&R 时序遗留问题：功能通过不等于时序闭合

最后一次正式交付位流对应的 P&R 报告是：`pnr-report/ddr3_live_hdmi.tr`。
报告摘要仍为：

- **101 个 setup 违反端点**；
- **29 个 hold 违反端点**。

因此，本次结论必须严格写成：**功能实板验证通过，但完整静态时序报告尚未闭合。**

进一步分析发现：

1. 一部分 setup/hold 路径是 `camera_pclk ↔ ui100`、`pixel33 ↔ ui100` 的异步 FIFO 指针和单 bit 同步器路径；工具默认会分析 CDC。隔离实验加入精确异步时钟组后，摘要由 101/29 降为 76/18，但不能因此直接把所有 CDC 路径隐藏。
2. 最差 setup 约 **-2.189 ns**，集中在 Gowin DDR PHY 的 DLL step、DQS 和校准内部路径。这些是生成的专用 PHY 逻辑，不能直接修改网表或用全局 false path 掩盖。
3. 展开报告还有大量 reset recovery 违反，最差约 **-6.392 ns**，主要涉及 DDR PHY reset/校准与 400 MHz 时钟关系。reset recovery 需要单独解决。
4. 将所有 PLL 输出简单改成 generated clock 的隔离实验结果更差，为 143 setup、60 hold、176 recovery，因此没有把该实验约束用于最终位流。

### 待解决事项

- 对真实异步时钟域、FIFO 同步级和单 bit mailbox 做精确 CDC 约束与结构审查；
- 按 Gowin 官方同器件 DDR3 基线核对 PHY 配置、mDRP、reset 和 P&R 选项；
- 解决或解释 DDR PHY 内部 setup/hold/recovery 路径；
- 对各时钟域实行异步拉低、同步释放的 reset 方案；
- 重新 P&R 后进行 HDMI 实景、D6/D7、长时间运行和复位实测。

在上述事项完成前，不应把本位流称为“完整时序签核通过”，也不应直接写入配置 Flash 作为最终量产固件。

## 5. 目录文件说明

- `firmware/ddr3_live_hdmi.fs`：最终实板功能验证位流；
- `pnr-report/`：最后一次正式 P&R 报告及时序研究；
- `hardware-evidence/`：HDMI 实景照片和用户验证记录；
- `tests/`：仿真通过日志；
- `git-history/`：Git 提交和历史记录；
- `SHA256SUMS`：位流校验值。

本目录只保存证据和已编译产物，不执行 programmer，不修改配置 Flash。

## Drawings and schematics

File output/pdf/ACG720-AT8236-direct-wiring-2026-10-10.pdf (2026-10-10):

# ① 这 8 根线，直接照两端编号接

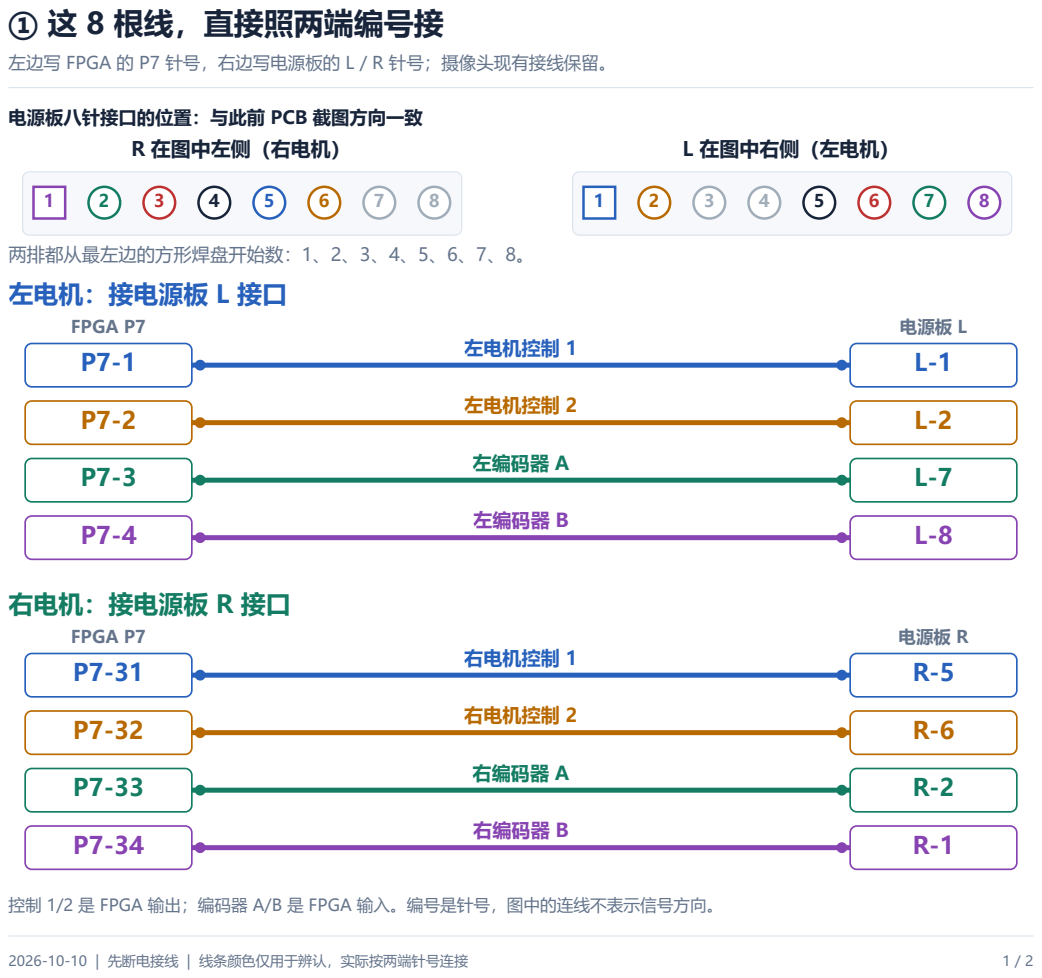
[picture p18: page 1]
2026-10-10 | 先断电接线 | 线条颜色仅用于辨认，实际按两端针号连接; R 在图中左侧（右电机）; L 在图中右侧（左电机）; FPGA P7; 电源板 L; L-1 左电机控制 1; L-2 左电机控制 2; L-7 左编码器 A; L-8 左编码器 B; 电源板 R; R-5 右电机控制 1; R-6 右电机控制 2; R-2 右编码器 A; R-1 右编码器 B

左边写 FPGA 的 P7 针号，右边写电源板的 L / R 针号；摄像头现有接线保留。

电源板八针接口的位置：与此前 PCB 截图方向一致

两排都从最左边的方形焊盘开始数：1、2、3、4、5、6、7、8。
左电机：接电源板 L 接口

右电机：接电源板 R 接口

控制 1/2 是 FPGA 输出；编码器 A/B 是 FPGA 输入。编号是针号，图中的连线不表示信号方向。

# ② 另外接电源、公共地和未用通道

## A. 若 P8 空闲，另接这两根线

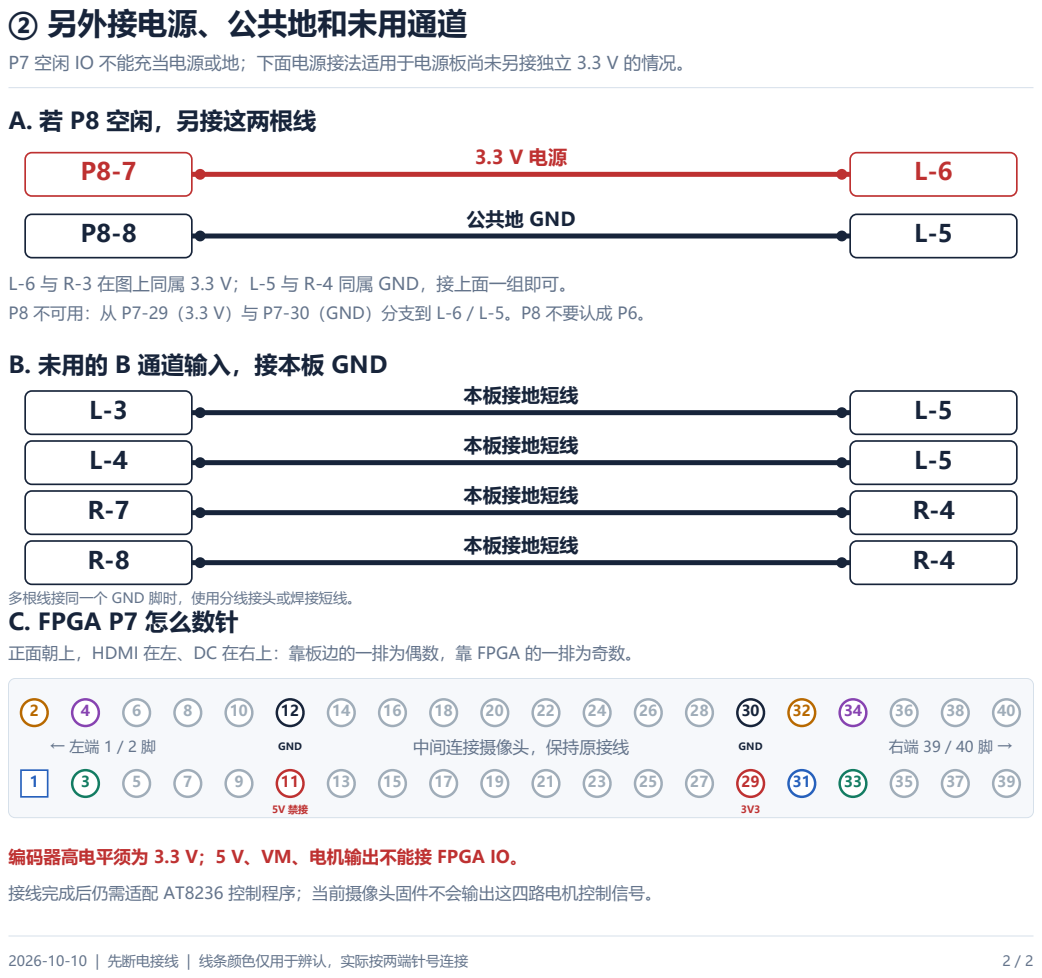
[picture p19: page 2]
2026-10-10 | 先断电接线 | 线条颜色仅用于辨认，实际按两端针号连接; L-5 公共地 GND; L-5 本板接地短线; R-4 本板接地短线; GND; 中间连接摄像头，保持原接线

P7 空闲 IO 不能充当电源或地；下面电源接法适用于电源板尚未另接独立 3.3 V 的情况。

L-6 与 R-3 在图上同属 3.3 V；L-5 与 R-4 同属 GND，接上面一组即可。
P8 不可用：从 P7-29（3.3 V）与 P7-30（GND）分支到 L-6 / L-5。P8 不要认成 P6。

B. 未用的 B 通道输入，接本板 GND

多根线接同一个 GND 脚时，使用分线接头或焊接短线。
C. FPGA P7 怎么数针

正面朝上，HDMI 在左、DC 在右上：靠板边的一排为偶数，靠 FPGA 的一排为奇数。

编码器高电平须为 3.3 V；5 V、VM、电机输出不能接 FPGA IO。

接线完成后仍需适配 AT8236 控制程序；当前摄像头固件不会输出这四路电机控制信号。

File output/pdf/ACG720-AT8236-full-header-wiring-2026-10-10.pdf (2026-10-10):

# 完整 FPGA P7 ＋ 电源板电机排针：直接连到对应针脚

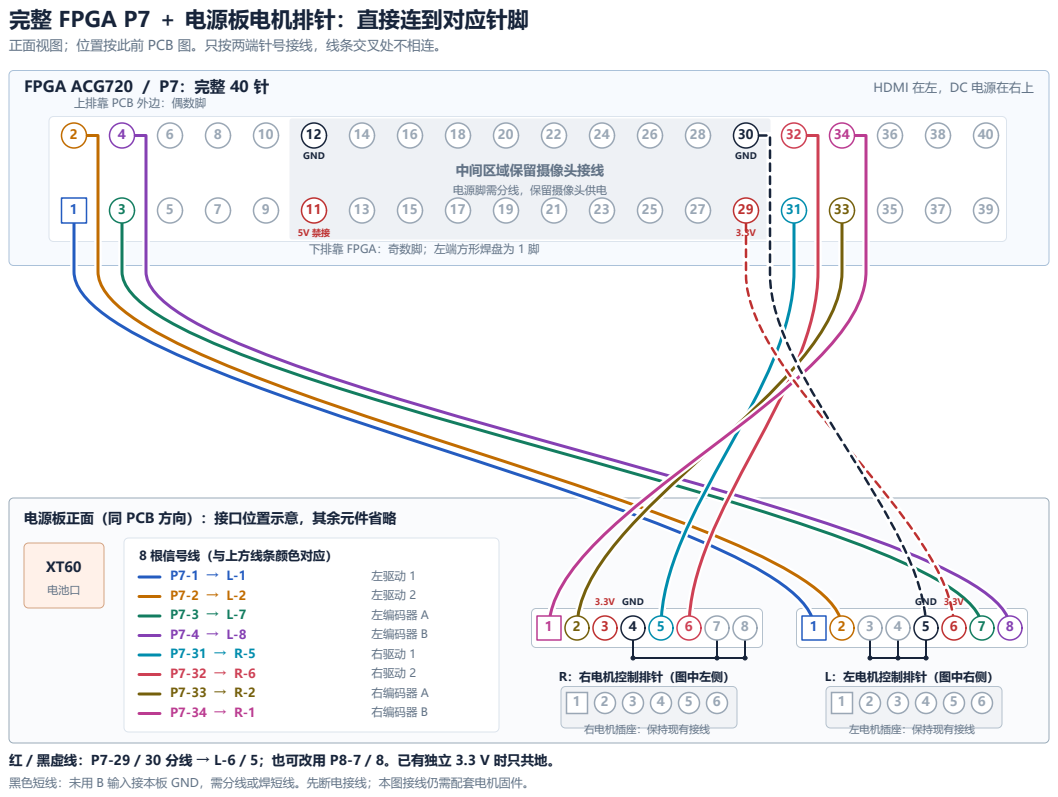
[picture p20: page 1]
FPGA ACG720 / P7：完整 40 针; HDMI 在左，DC 电源在右上; 中间区域保留摄像头接线; 电源脚需分线，保留摄像头供电; 电池口; R：右电机控制排针（图中左侧）; 右电机插座：保持现有接线; L：左电机控制排针（图中右侧）; 左电机插座：保持现有接线; GND; 8 根信号线（与上方线条颜色对应）; 左驱动 1; 左驱动 2; 左编码器 A; 左编码器 B; 右驱动 1; 右驱动 2; 右编码器 A; 右编码器 B

正面视图；位置按此前 PCB 图。只按两端针号接线，线条交叉处不相连。

上排靠 PCB 外边：偶数脚

下排靠 FPGA：奇数脚；左端方形焊盘为 1 脚

电源板正面（同 PCB 方向）：接口位置示意，其余元件省略

红 / 黑虚线：P7-29 / 30 分线 → L-6 / 5；也可改用 P8-7 / 8。已有独立 3.3 V 时只共地。
黑色短线：未用 B 输入接本板 GND，需分线或焊短线。先断电接线；本图接线仍需配套电机固件。

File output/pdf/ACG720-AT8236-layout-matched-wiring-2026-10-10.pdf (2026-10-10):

# 按你的截图摆放：完整 P7 与电源板排针同图连线

FPGA ACG720 / P7：完整 40 针 | 正面：HDMI 在左，DC 电源在右上

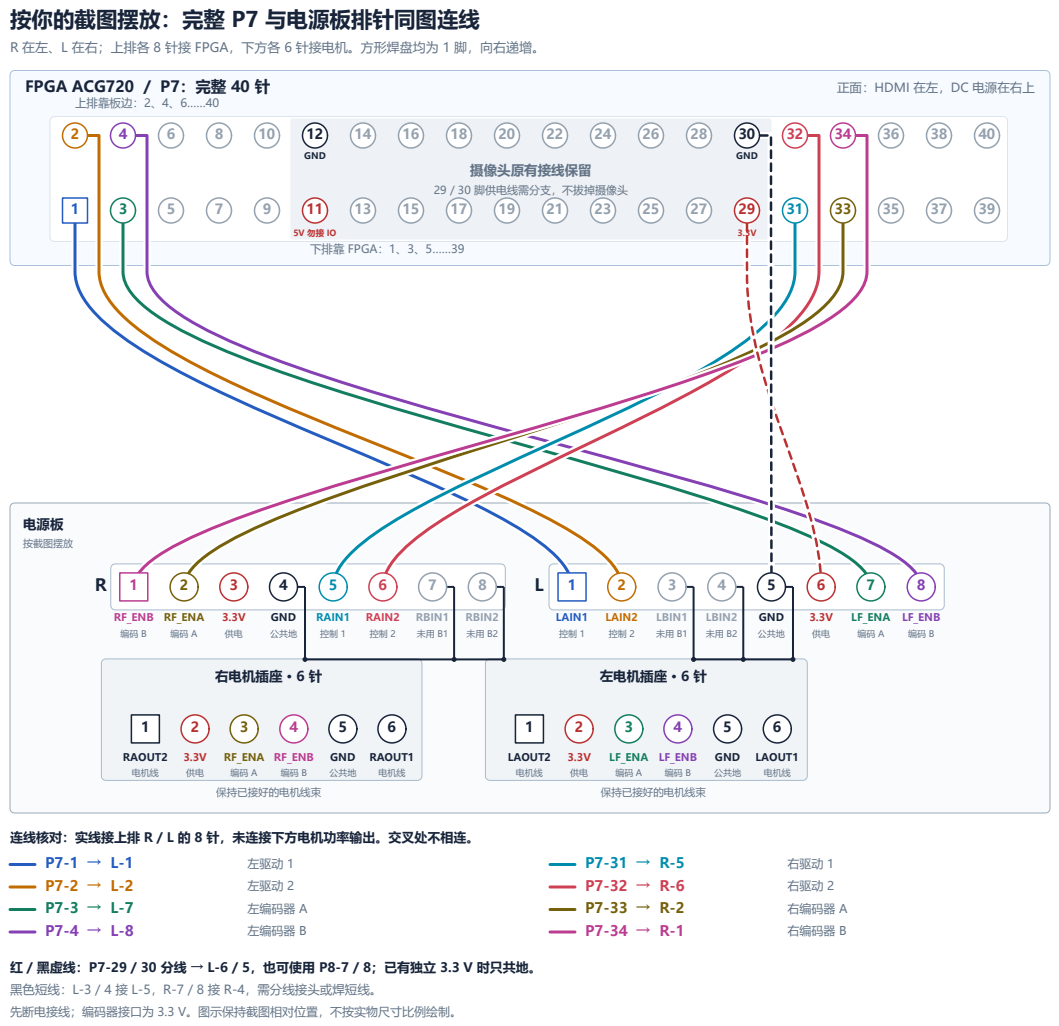
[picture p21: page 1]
上排靠板边：2、4、6……40; 下排靠 FPGA：1、3、5……39; 摄像头原有接线保留; 29 / 30 脚供电线需分支，不拔掉摄像头; 电源板; 按截图摆放; 右电机插座 · 6 针; 保持已接好的电机线束; 左电机插座 · 6 针; GND; RF_ENB; RF_ENA; 公共地; RAIN1; RAIN2; RBIN1; RBIN2; LAIN1; LAIN2; LBIN1; LBIN2; LF_ENA; LF_ENB; RAOUT2; 电机线; RAOUT1; LAOUT2; LAOUT1; 左驱动 1; 左驱动 2; 左编码器 A; 左编码器 B; 右驱动 1; 右驱动 2; 右编码器 A; 右编码器 B

R 在左、L 在右；上排各 8 针接 FPGA，下方各 6 针接电机。方形焊盘均为 1 脚，向右递增。

连线核对：实线接上排 R / L 的 8 针，未连接下方电机功率输出。交叉处不相连。

红 / 黑虚线：P7-29 / 30 分线 → L-6 / 5，也可使用 P8-7 / 8；已有独立 3.3 V 时只共地。
黑色短线：L-3 / 4 接 L-5，R-7 / 8 接 R-4，需分线接头或焊短线。
先断电接线；编码器接口为 3.3 V。图示保持截图相对位置，不按实物尺寸比例绘制。

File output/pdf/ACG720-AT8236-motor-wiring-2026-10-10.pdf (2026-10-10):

# ① 电源板：接下面的 R / L 八针排针

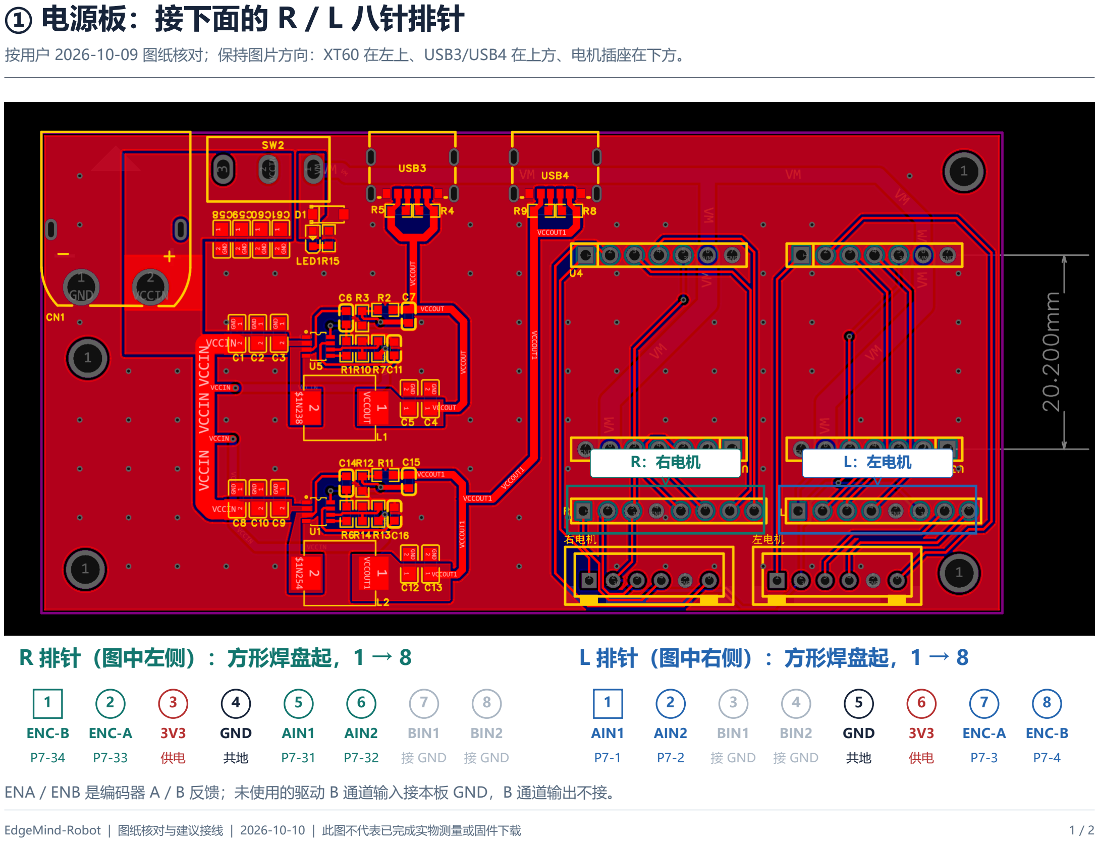
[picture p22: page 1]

按用户 2026-10-09 图纸核对；保持图片方向：XT60 在左上、USB3/USB4 在上方、电机插座在下方。

EdgeMind-Robot | 图纸核对与建议接线 | 2026-10-10 | 此图不代表已完成实物测量或固件下载 | 1 / 2
R：右电机 | L：左电机

## R 排针（图中左侧）：方形焊盘起，1 → 8

1

ENC-B

P7-34

2

ENC-A

P7-33

3

3V3

供电

4

GND

共地

5

AIN1

P7-31

6

AIN2

P7-32

7

BIN1

接 GND

8

BIN2

接 GND

## L 排针（图中右侧）：方形焊盘起，1 → 8

1

AIN1

P7-1

2

AIN2

P7-2

3

BIN1

接 GND

4

BIN2

接 GND

5

GND

共地

6

3V3

供电

7

ENC-A

P7-3

8

ENC-B

P7-4

ENA / ENB 是编码器 A / B 反馈；未使用的驱动 B 通道输入接本板 GND，B 通道输出不接。

# ② FPGA：使用 P7 两端空闲 IO，电源另接

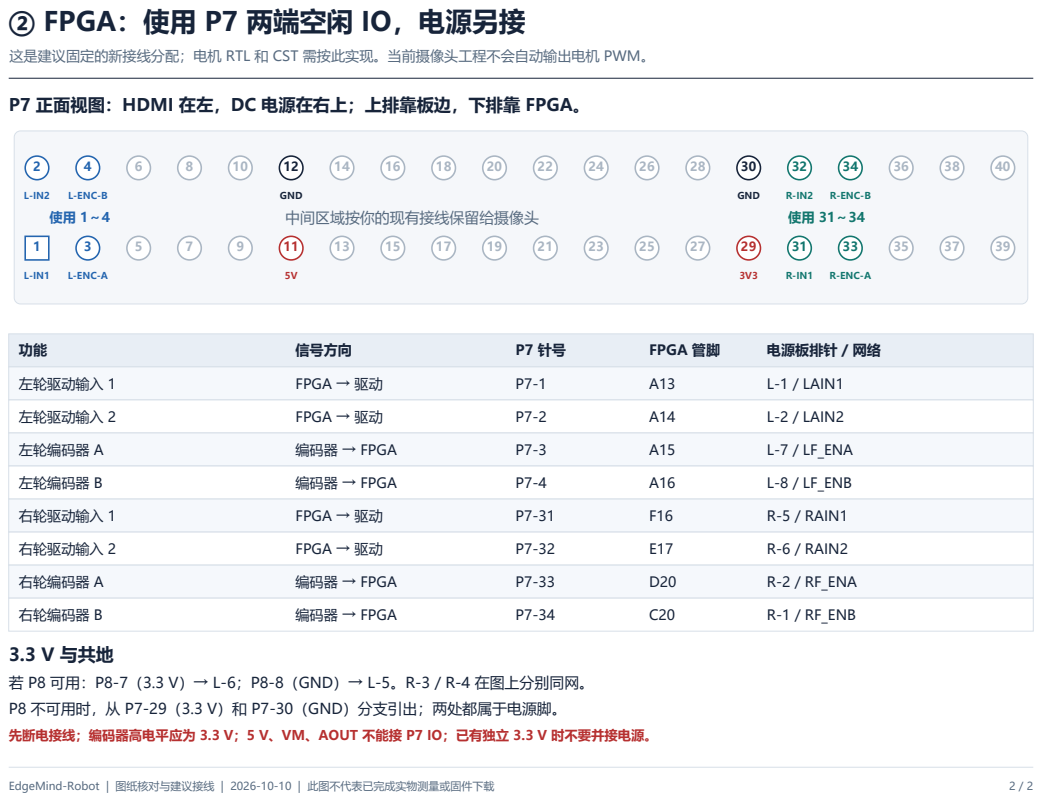
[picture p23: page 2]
EdgeMind-Robot | 图纸核对与建议接线 | 2026-10-10 | 此图不代表已完成实物测量或固件下载; L-ENC-B; L-ENC-A; GND; R-ENC-B; R-ENC-A; 中间区域按你的现有接线保留给摄像头; 信号方向; FPGA 管脚; 电源板排针 / 网络; 左轮驱动输入 1; FPGA → 驱动; L-1 / LAIN1; 左轮驱动输入 2; L-2 / LAIN2; 左轮编码器 A; 编码器 → FPGA; L-7 / LF_ENA; 左轮编码器 B; L-8 / LF_ENB; 右轮驱动输入 1; R-5 / RAIN1; 右轮驱动输入 2; R-6 / RAIN2; 右轮编码器 A; R-2 / RF_ENA; 右轮编码器 B; R-1 / RF_ENB; 3.3 V 与共地

这是建议固定的新接线分配；电机 RTL 和 CST 需按此实现。当前摄像头工程不会自动输出电机 PWM。

P7 正面视图：HDMI 在左，DC 电源在右上；上排靠板边，下排靠 FPGA。

若 P8 可用：P8-7（3.3 V）→ L-6；P8-8（GND）→ L-5。R-3 / R-4 在图上分别同网。
P8 不可用时，从 P7-29（3.3 V）和 P7-30（GND）分支引出；两处都属于电源脚。
先断电接线；编码器高电平应为 3.3 V；5 V、VM、AOUT 不能接 P7 IO；已有独立 3.3 V 时不要并接电源。

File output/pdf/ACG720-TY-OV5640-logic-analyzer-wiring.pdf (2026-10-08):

# ① 开发板 P7：先找位置，再从 1 / 2 脚开始数

### P7 / GPIO0

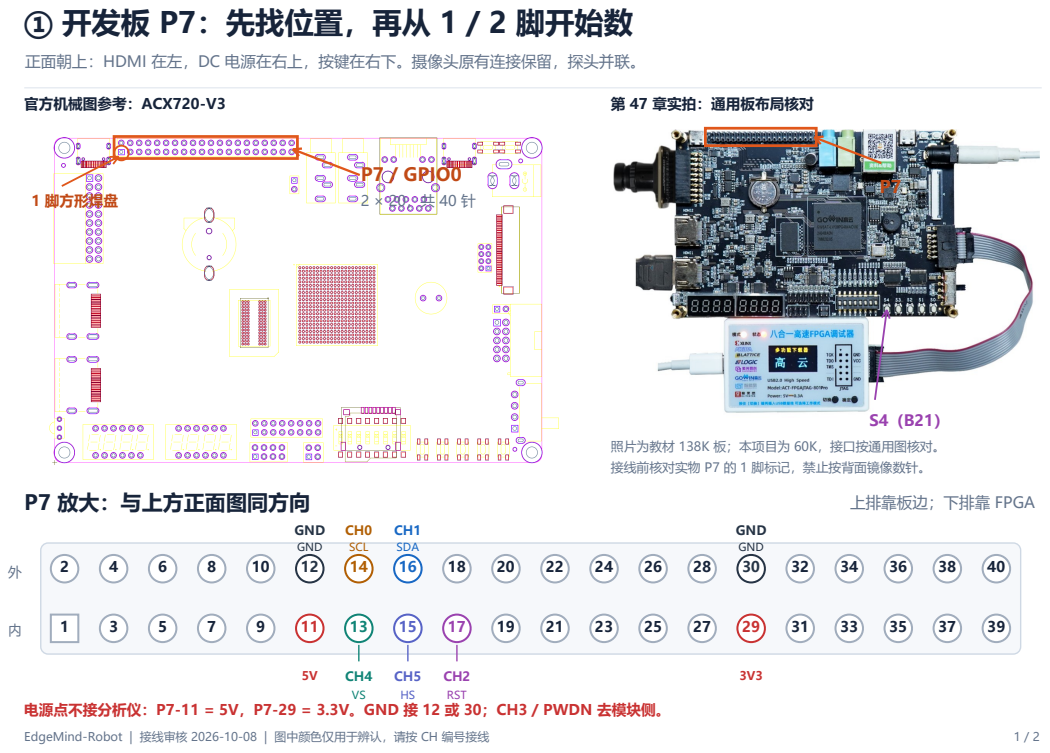
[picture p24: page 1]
EdgeMind-Robot | 接线审核 2026-10-08 | 图中颜色仅用于辨认，请按 CH 编号接线; 官方机械图参考：ACX720-V3; 1 脚方形焊盘; 第 47 章实拍：通用板布局核对; P7 放大：与上方正面图同方向; 上排靠板边；下排靠 FPGA; GND GND; CH0 SCL; CH1 SDA; RST

正面朝上：HDMI 在左，DC 电源在右上，按键在右下。摄像头原有连接保留，探头并联。

照片为教材 138K 板；本项目为 60K，接口按通用图核对。
接线前核对实物 P7 的 1 脚标记，禁止按背面镜像数针。

电源点不接分析仪：P7-11 = 5V，P7-29 = 3.3V。GND 接 12 或 30；CH3 / PWDN 去模块侧。

# ② TY-OV5640：模块侧也能并联探头

## 逻辑分析仪接线表（每路选择一端接）

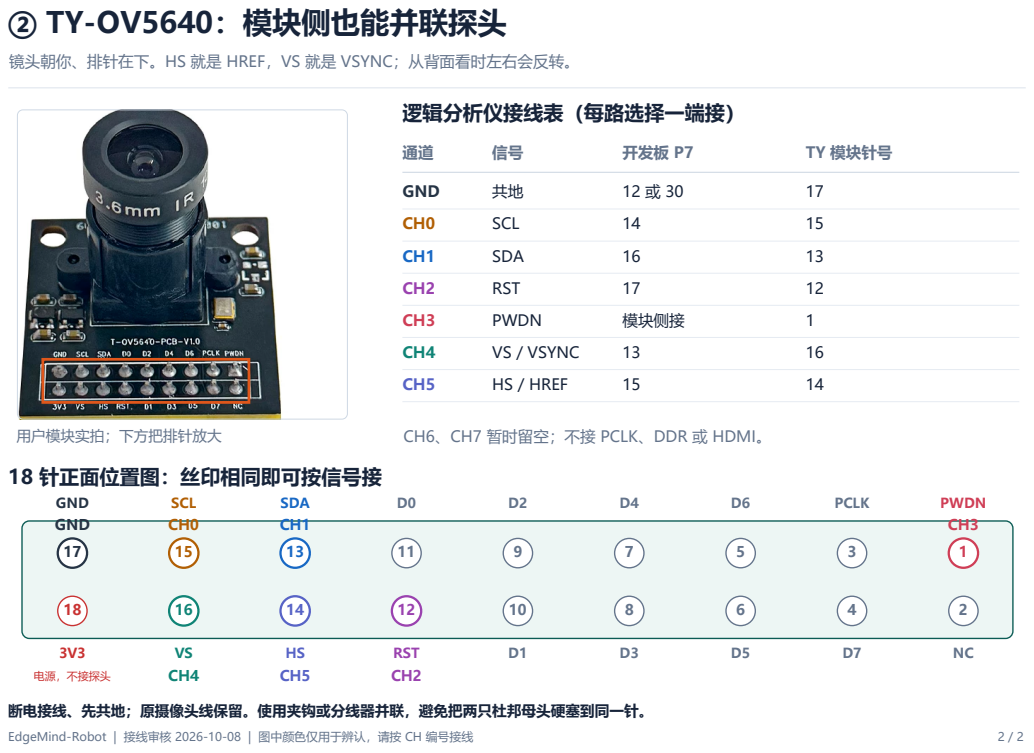
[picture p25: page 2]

镜头朝你、排针在下。HS 就是 HREF，VS 就是 VSYNC；从背面看时左右会反转。

CH6、CH7 暂时留空；不接 PCLK、DDR 或 HDMI。

断电接线、先共地；原摄像头线保留。使用夹钩或分线器并联，避免把两只杜邦母头硬塞到同一针。

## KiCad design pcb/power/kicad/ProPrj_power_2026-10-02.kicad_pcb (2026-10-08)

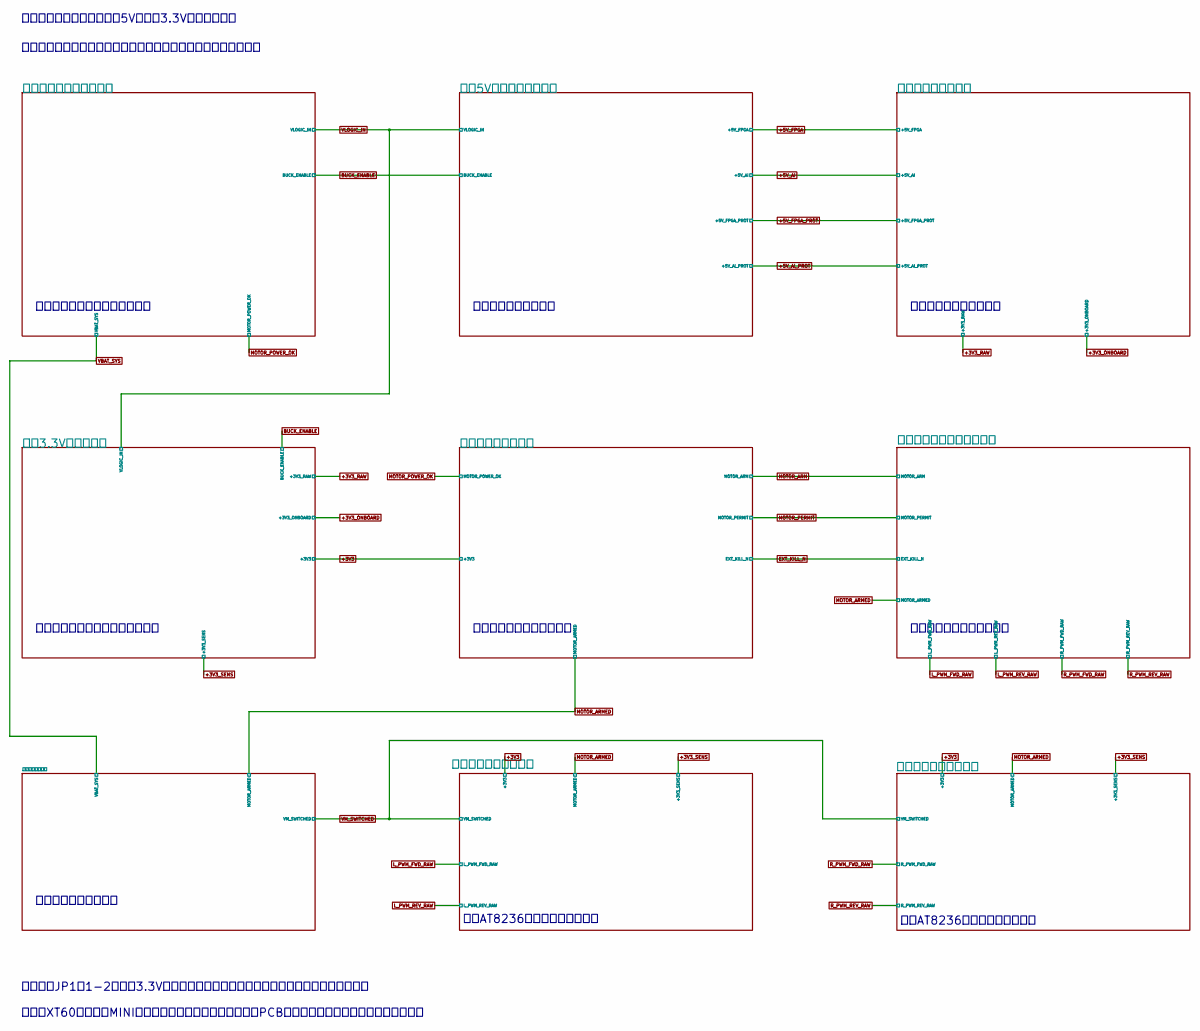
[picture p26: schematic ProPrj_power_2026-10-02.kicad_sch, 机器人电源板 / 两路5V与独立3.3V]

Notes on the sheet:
独立降压、跳帽选择与传感器滤波
默认短接JP1的1-2：板载3.3V。只安装一个跳帽；电机故障恢复后须重新发解锁脉冲。
右侧AT8236、编码器与电流监测
板载总保险、防反接与电压窗口
动力总开关与回生泄放
急停、上电复位与解锁锁存
实线为实际层级网络连接；远距离控制、监测信号采用同名标签。
输出过压与动力过流检测
左侧AT8236、编码器与电流监测
逻辑板控制与电源监测接口
两路降压与六针供电口
电池经XT60接入板载MINI总保险；单体电芯保护仍须落实。PCB封装与网络已同步，布局布线待完成。
电源板功能连接总图：两路5V、独立3.3V与双电机驱动

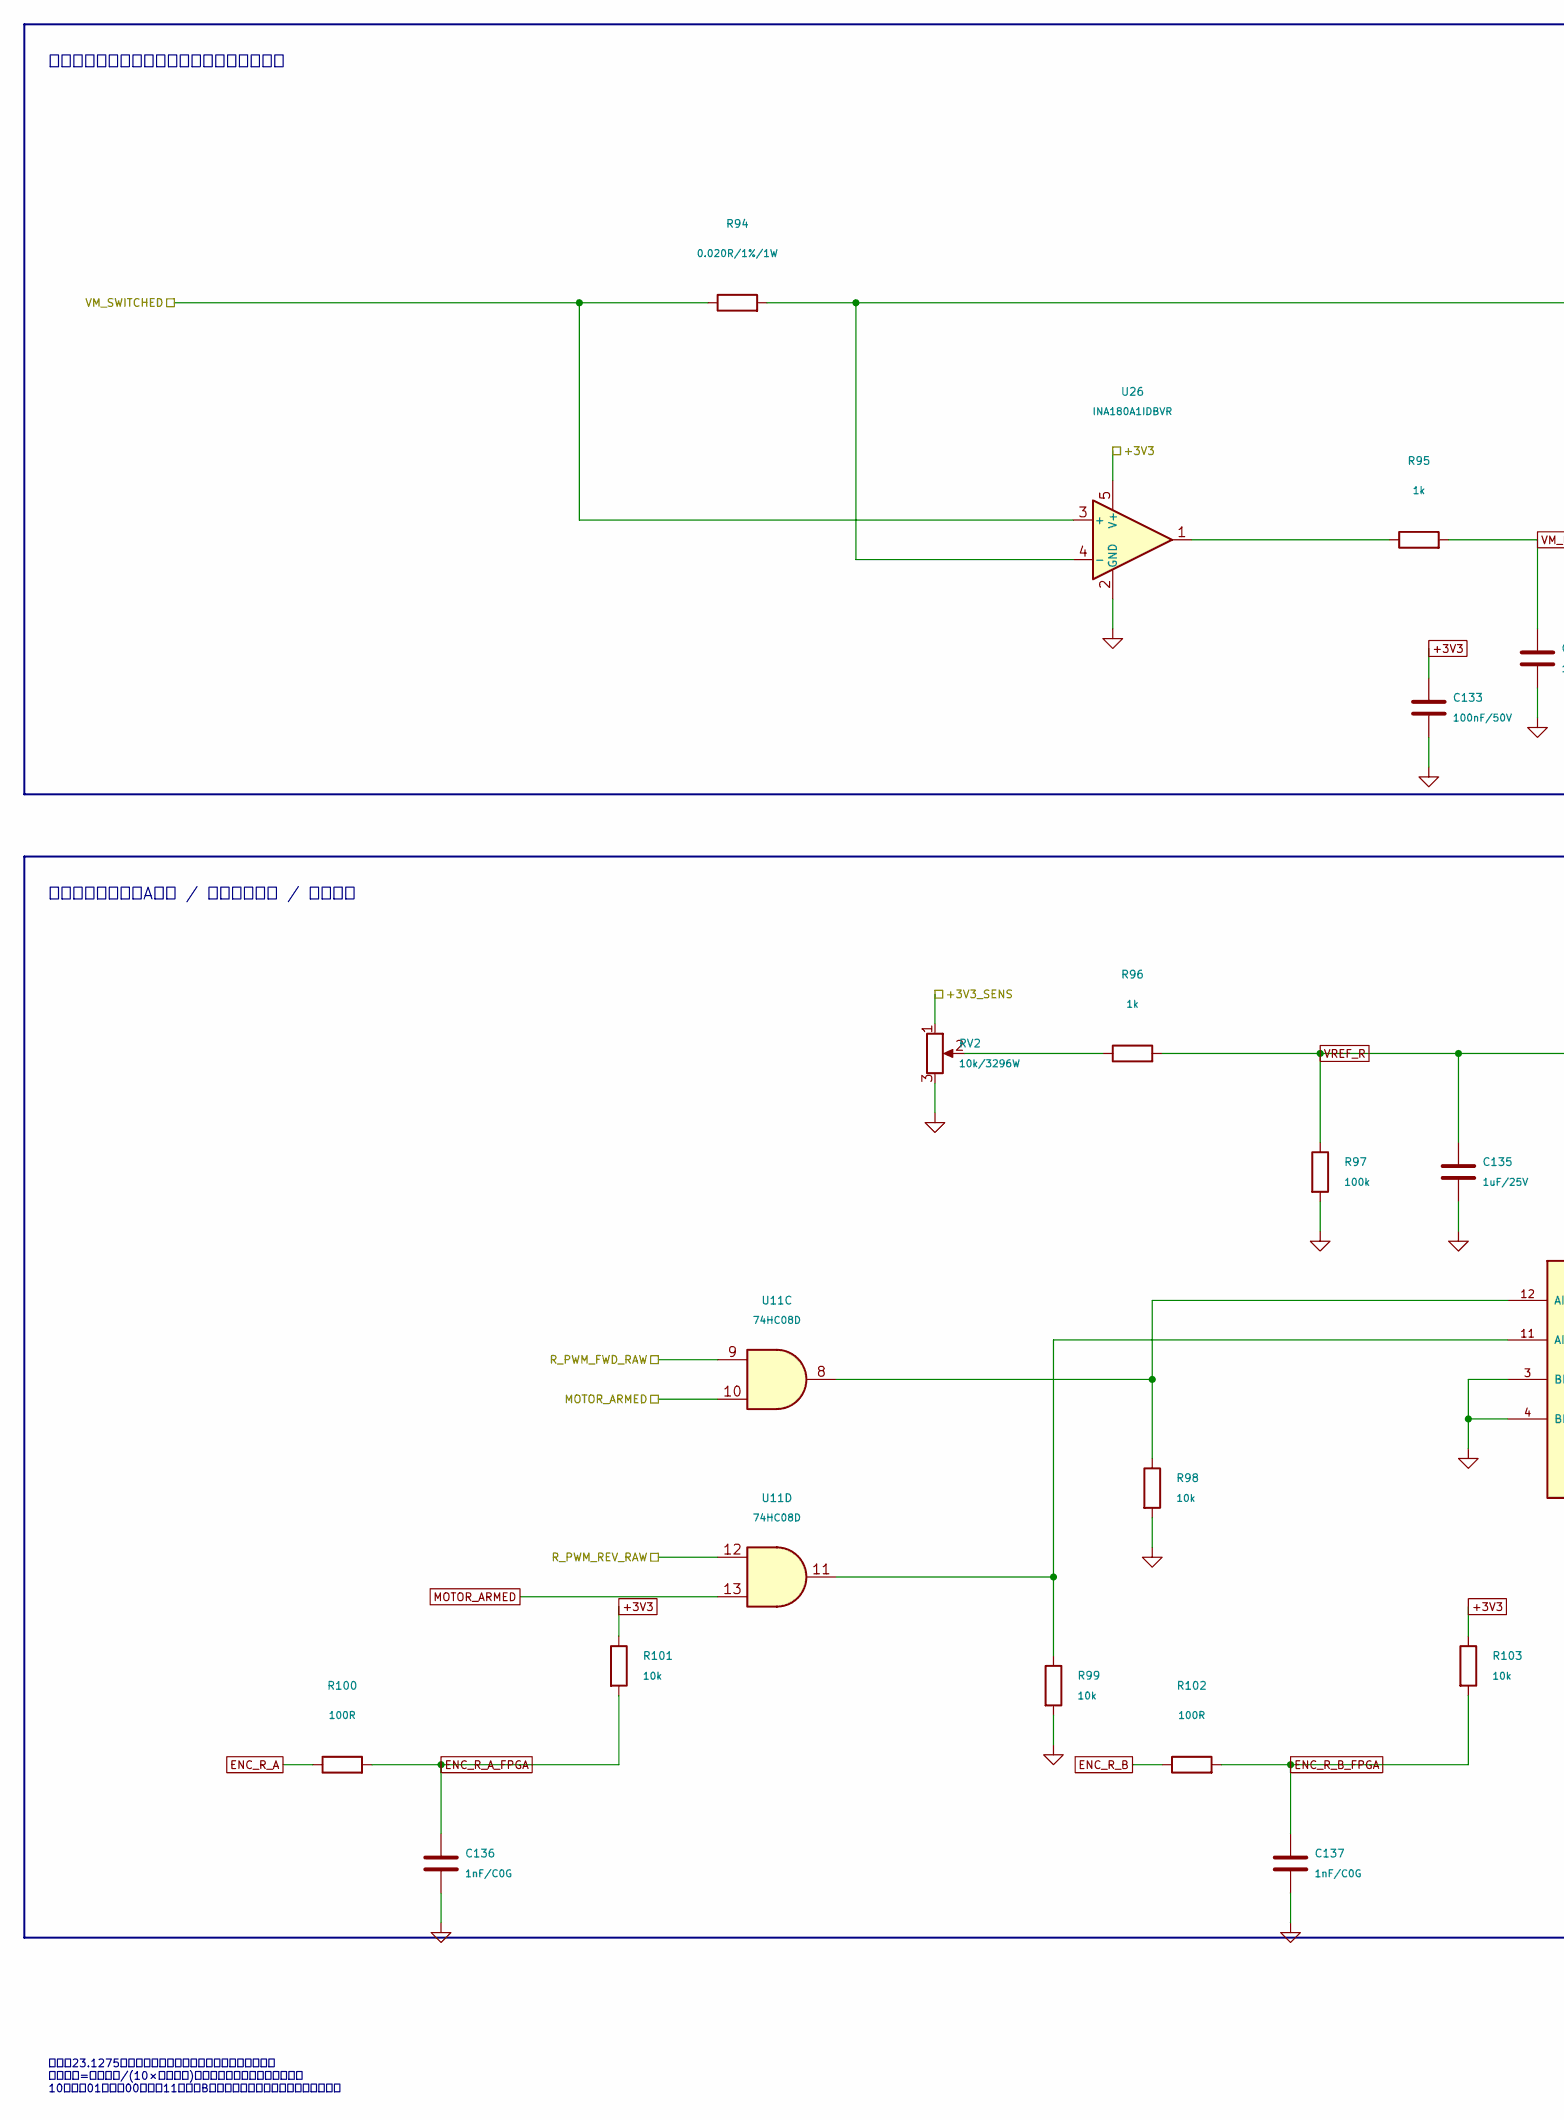
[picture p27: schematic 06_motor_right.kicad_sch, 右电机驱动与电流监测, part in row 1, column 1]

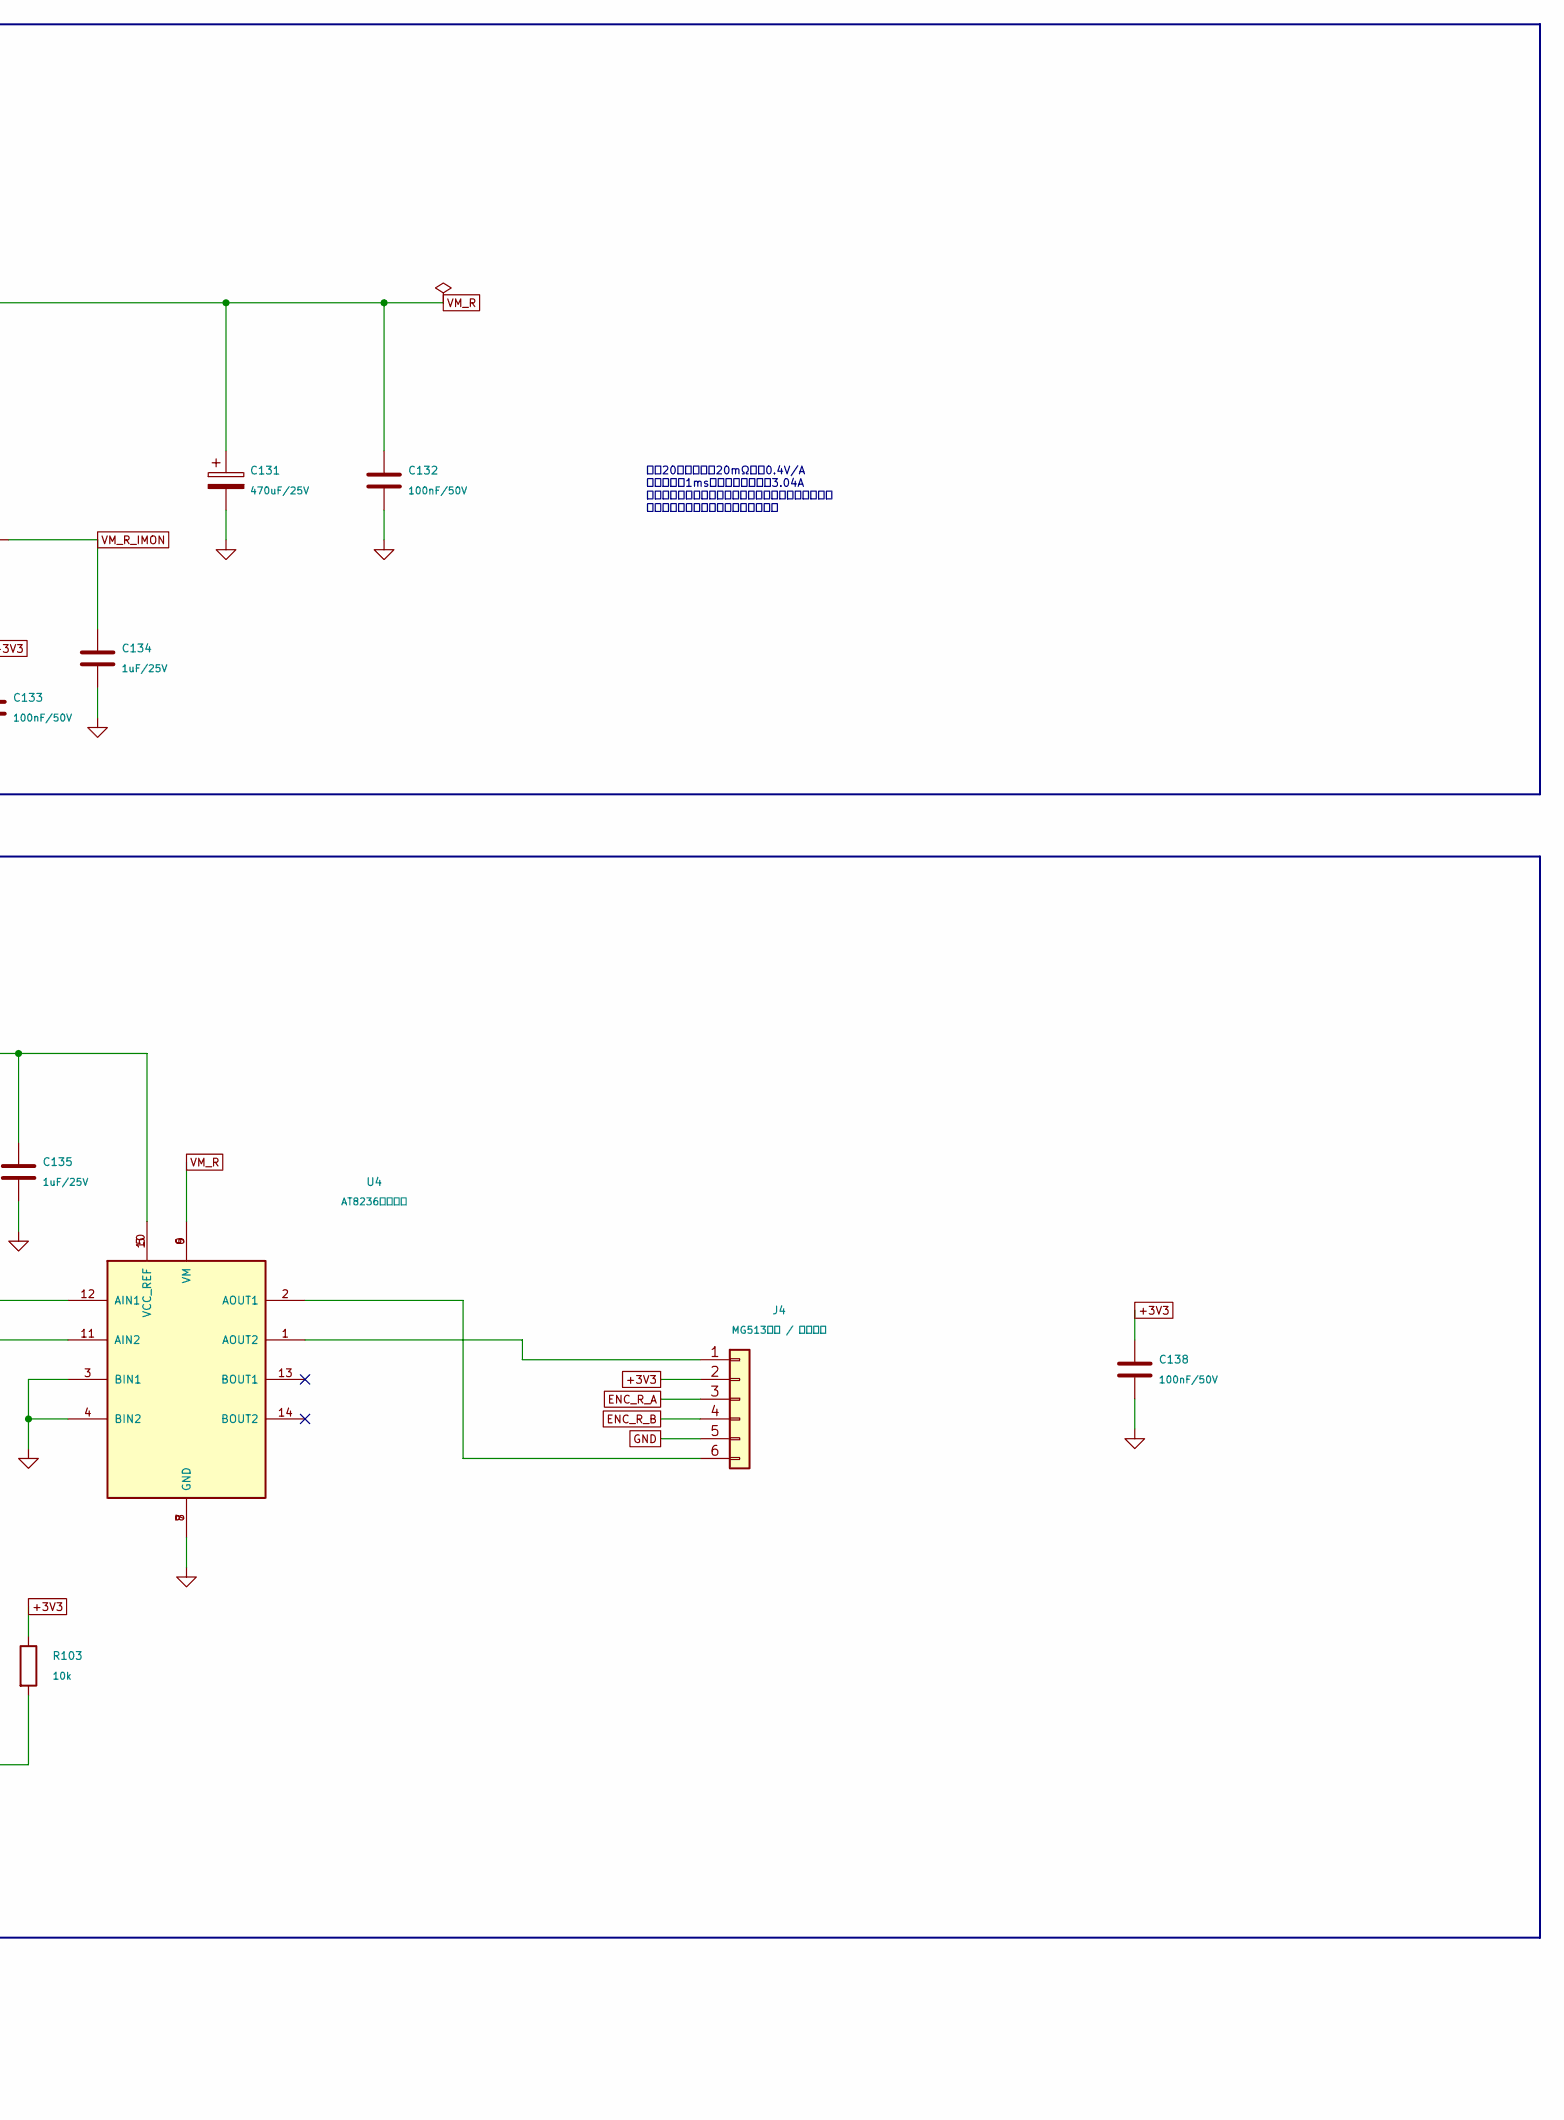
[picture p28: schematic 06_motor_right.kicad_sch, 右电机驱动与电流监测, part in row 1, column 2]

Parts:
C131: 470uF/25V; CP_Radial_D10.0mm_P5.00mm
C132, C133, C138: 100nF/50V; C_0805_2012Metric
C134, C135: 1uF/25V; C_0603_1608Metric
C136, C137: 1nF/C0G; C_0603_1608Metric
J4: MG513电机 / 核对线序; JST_XH_B6B-XH-A_1x06_P2.50mm_Vertical
R94: 0.020R/1%/1W; R_2512_6332Metric
R95, R96: 1k; R_0603_1608Metric
R97: 100k; R_0603_1608Metric
R98, R99, R101, R103: 10k; R_0603_1608Metric
R100, R102: 100R; R_0603_1608Metric
RV2: 10k/3296W; Potentiometer_Bourns_3296W_Vertical; MPN 3296W-1-103LF
U4: AT8236双路模块; AT8236_Dual_PinSocket_2x7_P2.54_Row23.1275mm; MPN AT8236 dual module / vendor-specific
U11: 74HC08D; SOIC-14_3.9x8.7mm_P1.27mm; MPN SN74HC08DR
U26: INA180A1IDBVR; SOT-23-5; MPN INA180A1IDBVR

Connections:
+3V3: C133.1, C138.1, J4.2, R101.1, R103.1, U26.5 (V+); also elsewhere on the board
+3V3_SENS: RV2.1; also elsewhere on the board
ENC_R_A: J4.3, R100.1
ENC_R_A_FPGA: C136.1, R100.2, R101.2; also elsewhere on the board
ENC_R_B: J4.4, R102.1
ENC_R_B_FPGA: C137.1, R102.2, R103.2; also elsewhere on the board
GND: C131.2, C132.2, C133.2, C134.2, C135.2, C136.2, C137.2, C138.2, J4.5, R97.2, R98.2, R99.2, RV2.3, U4.3 (BIN1), U4.4 (BIN2), U4.7 (GND), U4.8 (GND), U26.2 (GND); also elsewhere on the board
MOTOR_ARMED: U11.10, U11.13; also elsewhere on the board
unnamed: J4.1, U4.1 (AOUT2)
unnamed: J4.6, U4.2 (AOUT1)
unnamed: R95.1, U26.1
unnamed: R96.1, RV2.2
unnamed: R98.1, U4.12 (AIN1), U11.8
unnamed: R99.1, U4.11 (AIN2), U11.11
R_PWM_FWD_RAW: U11.9; also elsewhere on the board
R_PWM_REV_RAW: U11.12; also elsewhere on the board
VM_R: C131.1, C132.1, R94.2, U4.6 (VM), U4.9 (VM), U26.4 (-); also elsewhere on the board
VM_R_IMON: C134.1, R95.2; also elsewhere on the board
VM_SWITCHED: R94.1, U26.3 (+); also elsewhere on the board
VREF_R: C135.1, R96.2, R97.1, U4.5 (VCC_REF), U4.10 (VCC_REF)

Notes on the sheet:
排间距23.1275毫米，沿用原电路板；对排引脚编号已纠正。 限流电流=参考电压/(10×采样电阻)；安装电机前先测阻值并校准。 10正转、01反转、00滑行、11制动；B通道未用。编码器线序须与实物一致。
增益20，采样电阻20mΩ：约0.4V/A 输出滤波约1ms；母线过流阈值约3.04A 母线电流不同于绕组电流；滤波关断不能替代入口保护 入口总保险板载；模块内部限流须校准
右电机驱动：使用A通道 / 可调限流参考 / 双排排母
右电机：电子过流关断、电流监测与本地储能

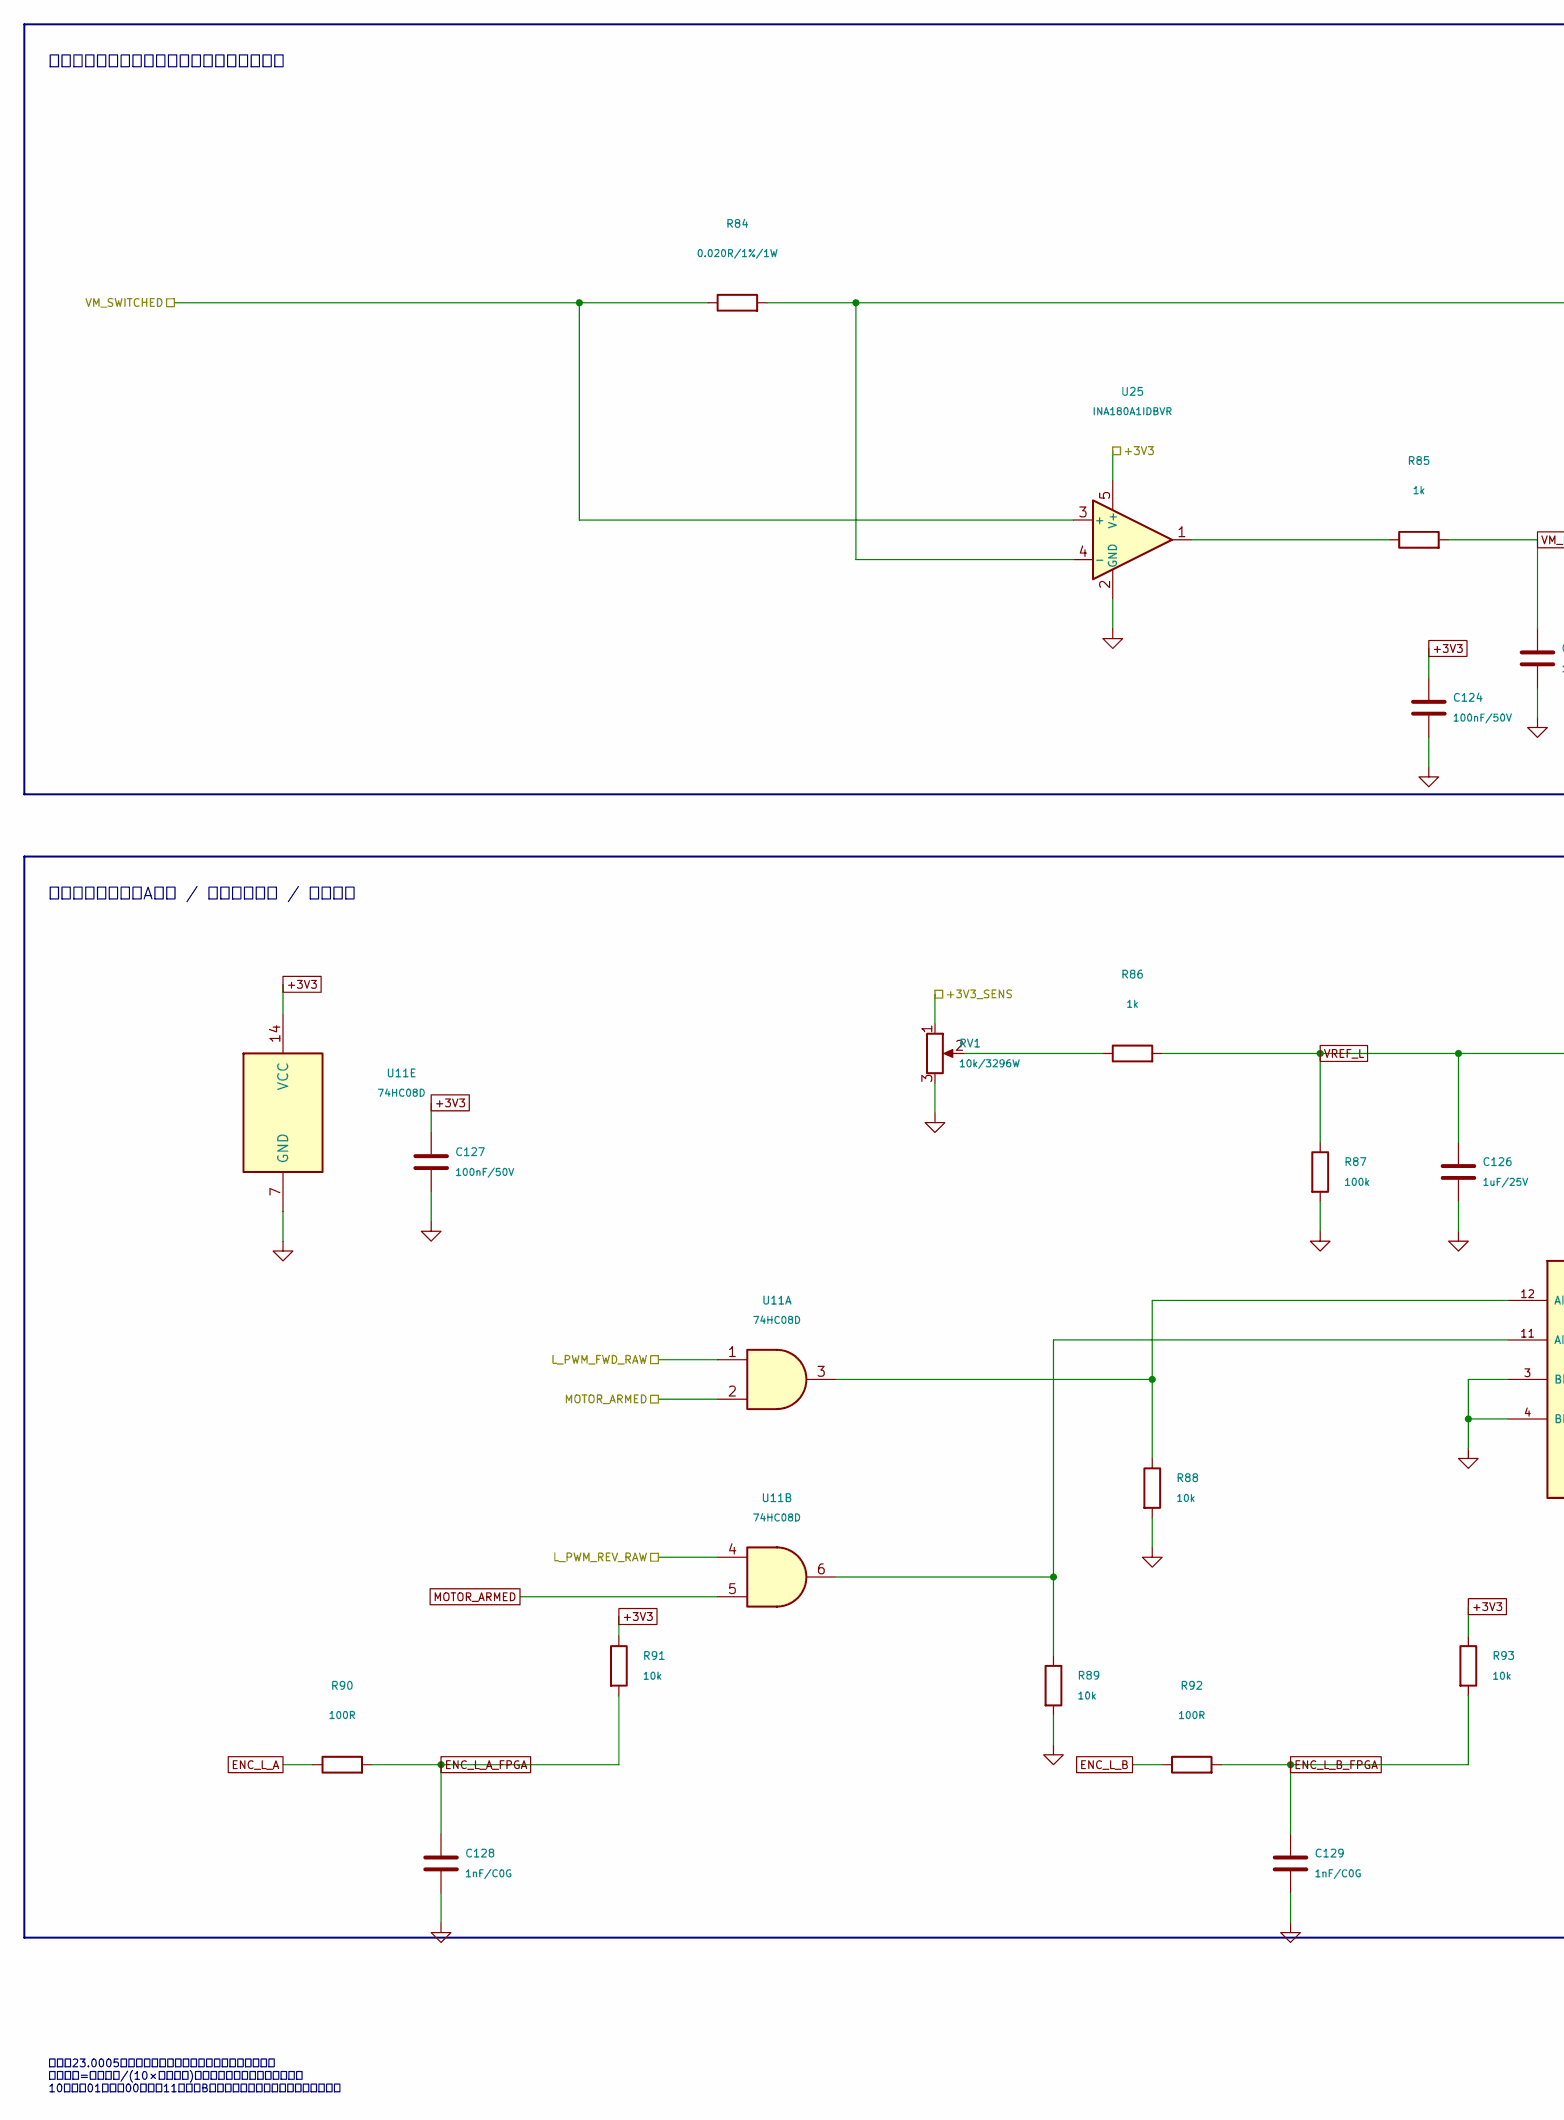
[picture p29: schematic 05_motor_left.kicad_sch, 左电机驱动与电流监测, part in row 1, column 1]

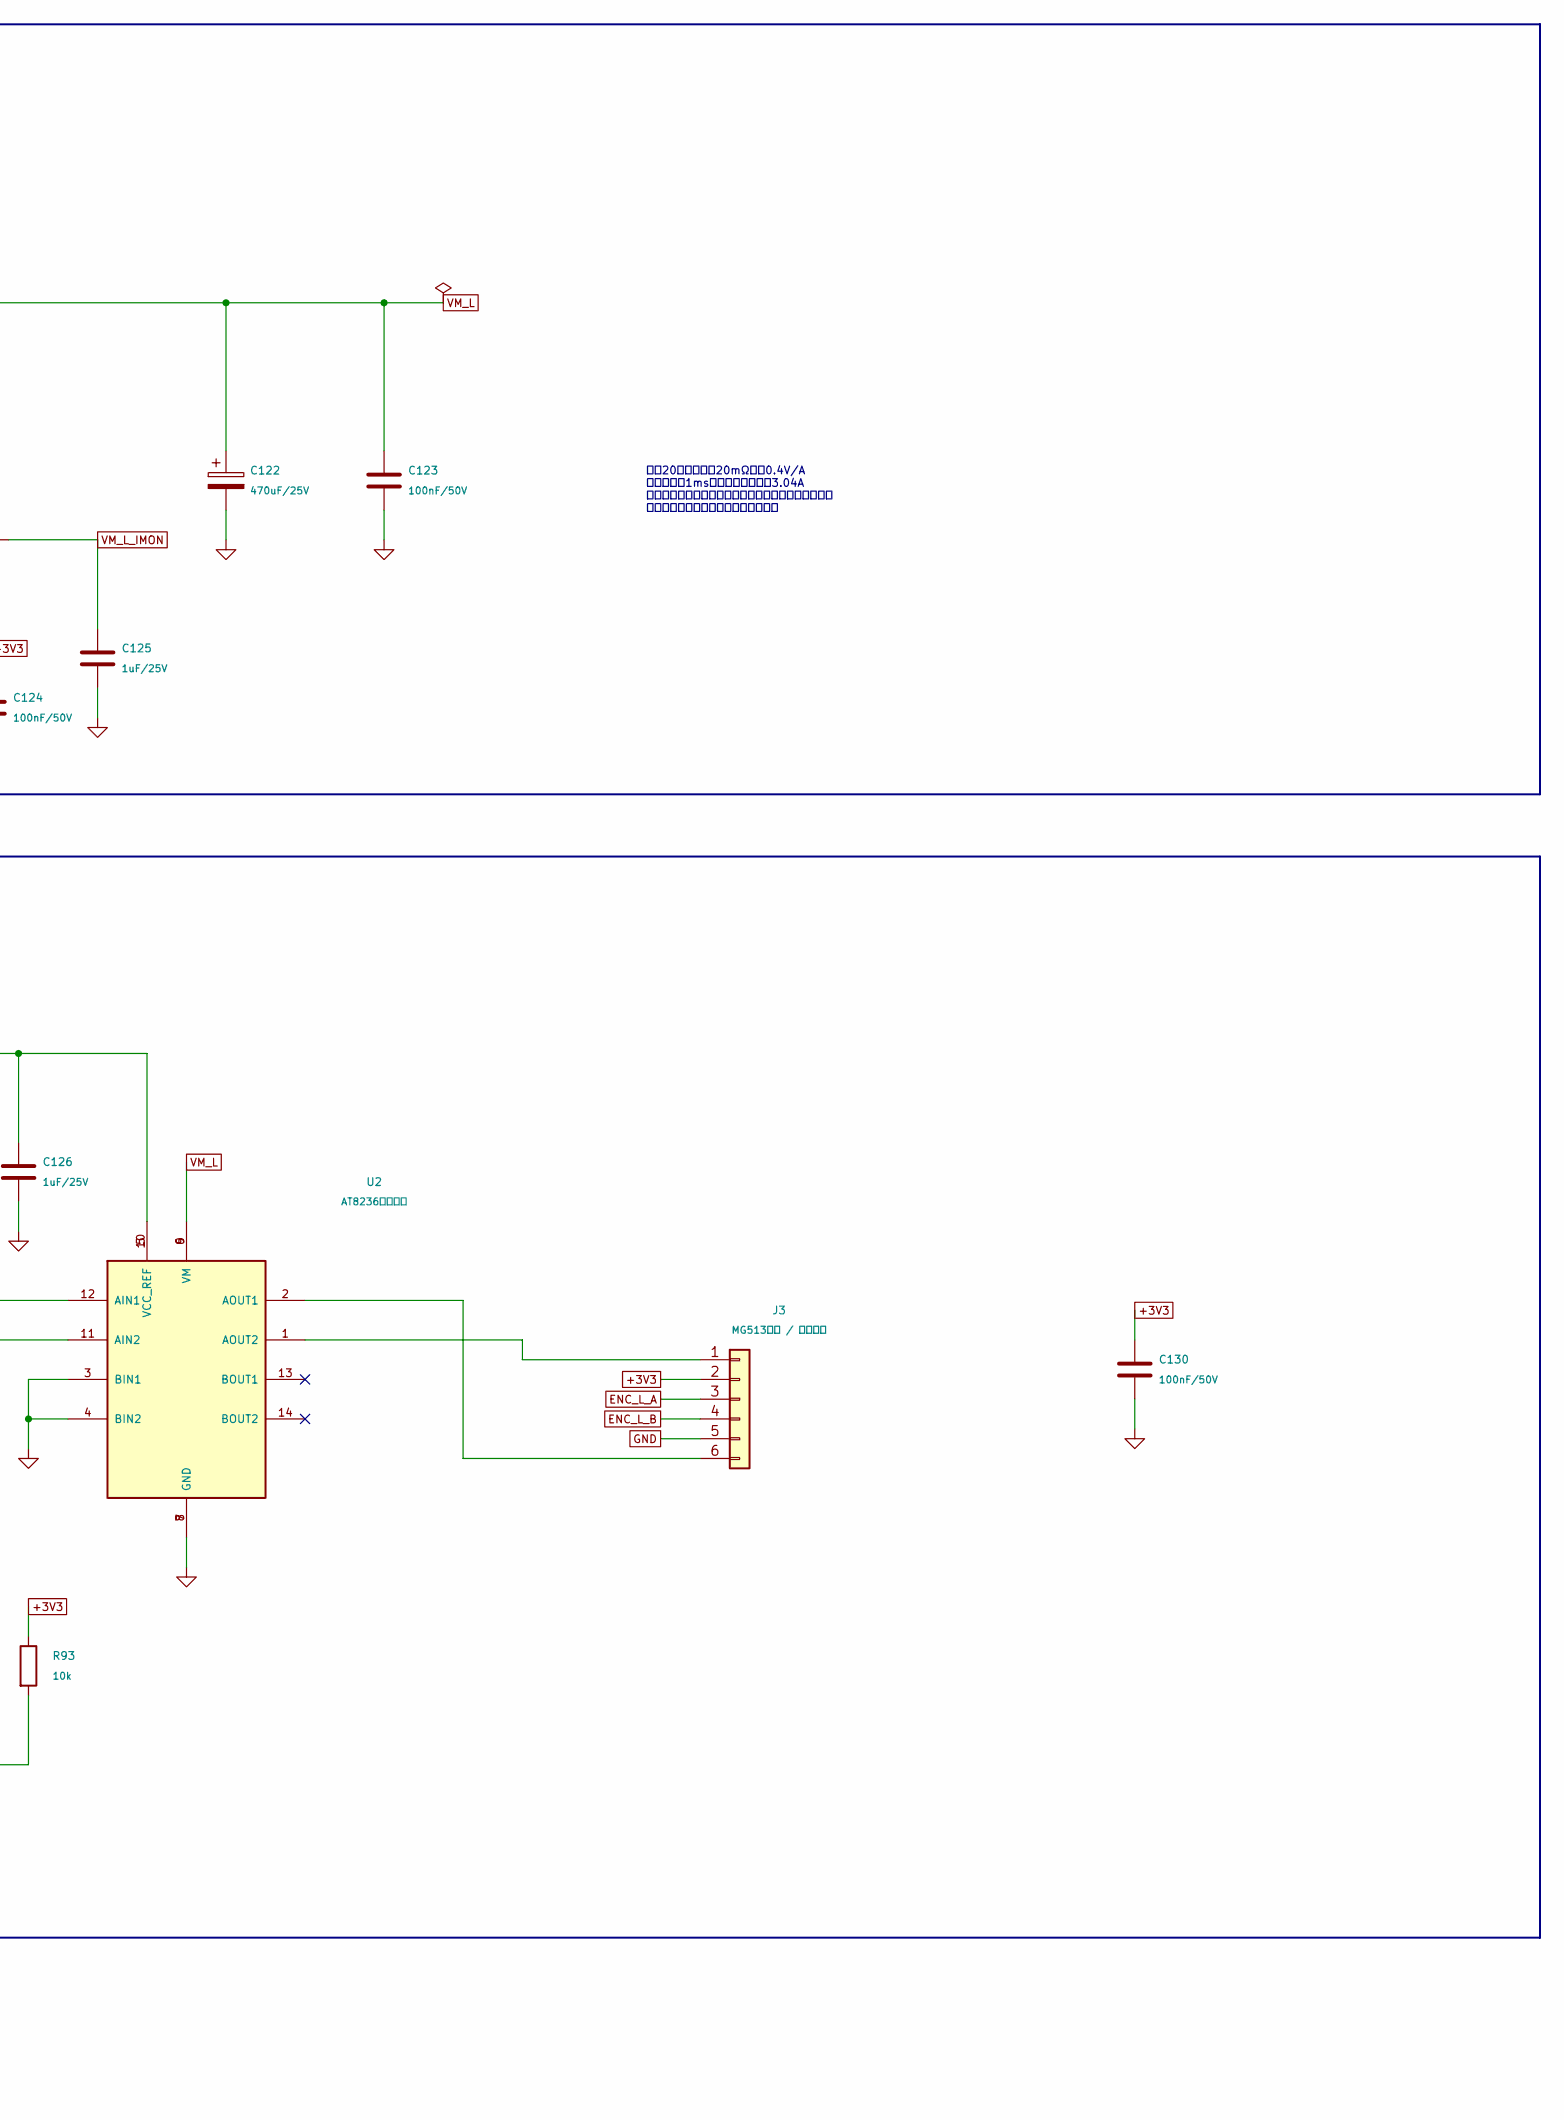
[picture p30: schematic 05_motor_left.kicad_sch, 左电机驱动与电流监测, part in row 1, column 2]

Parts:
C122: 470uF/25V; CP_Radial_D10.0mm_P5.00mm
C123, C124, C127, C130: 100nF/50V; C_0805_2012Metric
C125, C126: 1uF/25V; C_0603_1608Metric
C128, C129: 1nF/C0G; C_0603_1608Metric
J3: MG513电机 / 核对线序; JST_XH_B6B-XH-A_1x06_P2.50mm_Vertical
R84: 0.020R/1%/1W; R_2512_6332Metric
R85, R86: 1k; R_0603_1608Metric
R87: 100k; R_0603_1608Metric
R88, R89, R91, R93: 10k; R_0603_1608Metric
R90, R92: 100R; R_0603_1608Metric
RV1: 10k/3296W; Potentiometer_Bourns_3296W_Vertical; MPN 3296W-1-103LF
U2: AT8236双路模块; AT8236_Dual_PinSocket_2x7_P2.54_Row23.0005mm; MPN AT8236 dual module / vendor-specific
U11: 74HC08D; SOIC-14_3.9x8.7mm_P1.27mm; MPN SN74HC08DR
U25: INA180A1IDBVR; SOT-23-5; MPN INA180A1IDBVR

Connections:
+3V3: C124.1, C127.1, C130.1, J3.2, R91.1, R93.1, U11.14 (VCC), U25.5 (V+); also elsewhere on the board
+3V3_SENS: RV1.1; also elsewhere on the board
ENC_L_A: J3.3, R90.1
ENC_L_A_FPGA: C128.1, R90.2, R91.2; also elsewhere on the board
ENC_L_B: J3.4, R92.1
ENC_L_B_FPGA: C129.1, R92.2, R93.2; also elsewhere on the board
GND: C122.2, C123.2, C124.2, C125.2, C126.2, C127.2, C128.2, C129.2, C130.2, J3.5, R87.2, R88.2, R89.2, RV1.3, U2.3 (BIN1), U2.4 (BIN2), U2.7 (GND), U2.8 (GND), U11.7 (GND), U25.2 (GND); also elsewhere on the board
L_PWM_FWD_RAW: U11.1; also elsewhere on the board
L_PWM_REV_RAW: U11.4; also elsewhere on the board
MOTOR_ARMED: U11.2, U11.5; also elsewhere on the board
unnamed: J3.1, U2.1 (AOUT2)
unnamed: J3.6, U2.2 (AOUT1)
unnamed: R85.1, U25.1
unnamed: R86.1, RV1.2
unnamed: R88.1, U2.12 (AIN1), U11.3
unnamed: R89.1, U2.11 (AIN2), U11.6
VM_L: C122.1, C123.1, R84.2, U2.6 (VM), U2.9 (VM), U25.4 (-); also elsewhere on the board
VM_L_IMON: C125.1, R85.2; also elsewhere on the board
VM_SWITCHED: R84.1, U25.3 (+); also elsewhere on the board
VREF_L: C126.1, R86.2, R87.1, U2.5 (VCC_REF), U2.10 (VCC_REF)

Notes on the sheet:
增益20，采样电阻20mΩ：约0.4V/A 输出滤波约1ms；母线过流阈值约3.04A 母线电流不同于绕组电流；滤波关断不能替代入口保护 入口总保险板载；模块内部限流须校准
左电机驱动：使用A通道 / 可调限流参考 / 双排排母
排间距23.0005毫米，沿用原电路板；对排引脚编号已纠正。 限流电流=参考电压/(10×采样电阻)；安装电机前先测阻值并校准。 10正转、01反转、00滑行、11制动；B通道未用。编码器线序须与实物一致。
左电机：电子过流关断、电流监测与本地储能

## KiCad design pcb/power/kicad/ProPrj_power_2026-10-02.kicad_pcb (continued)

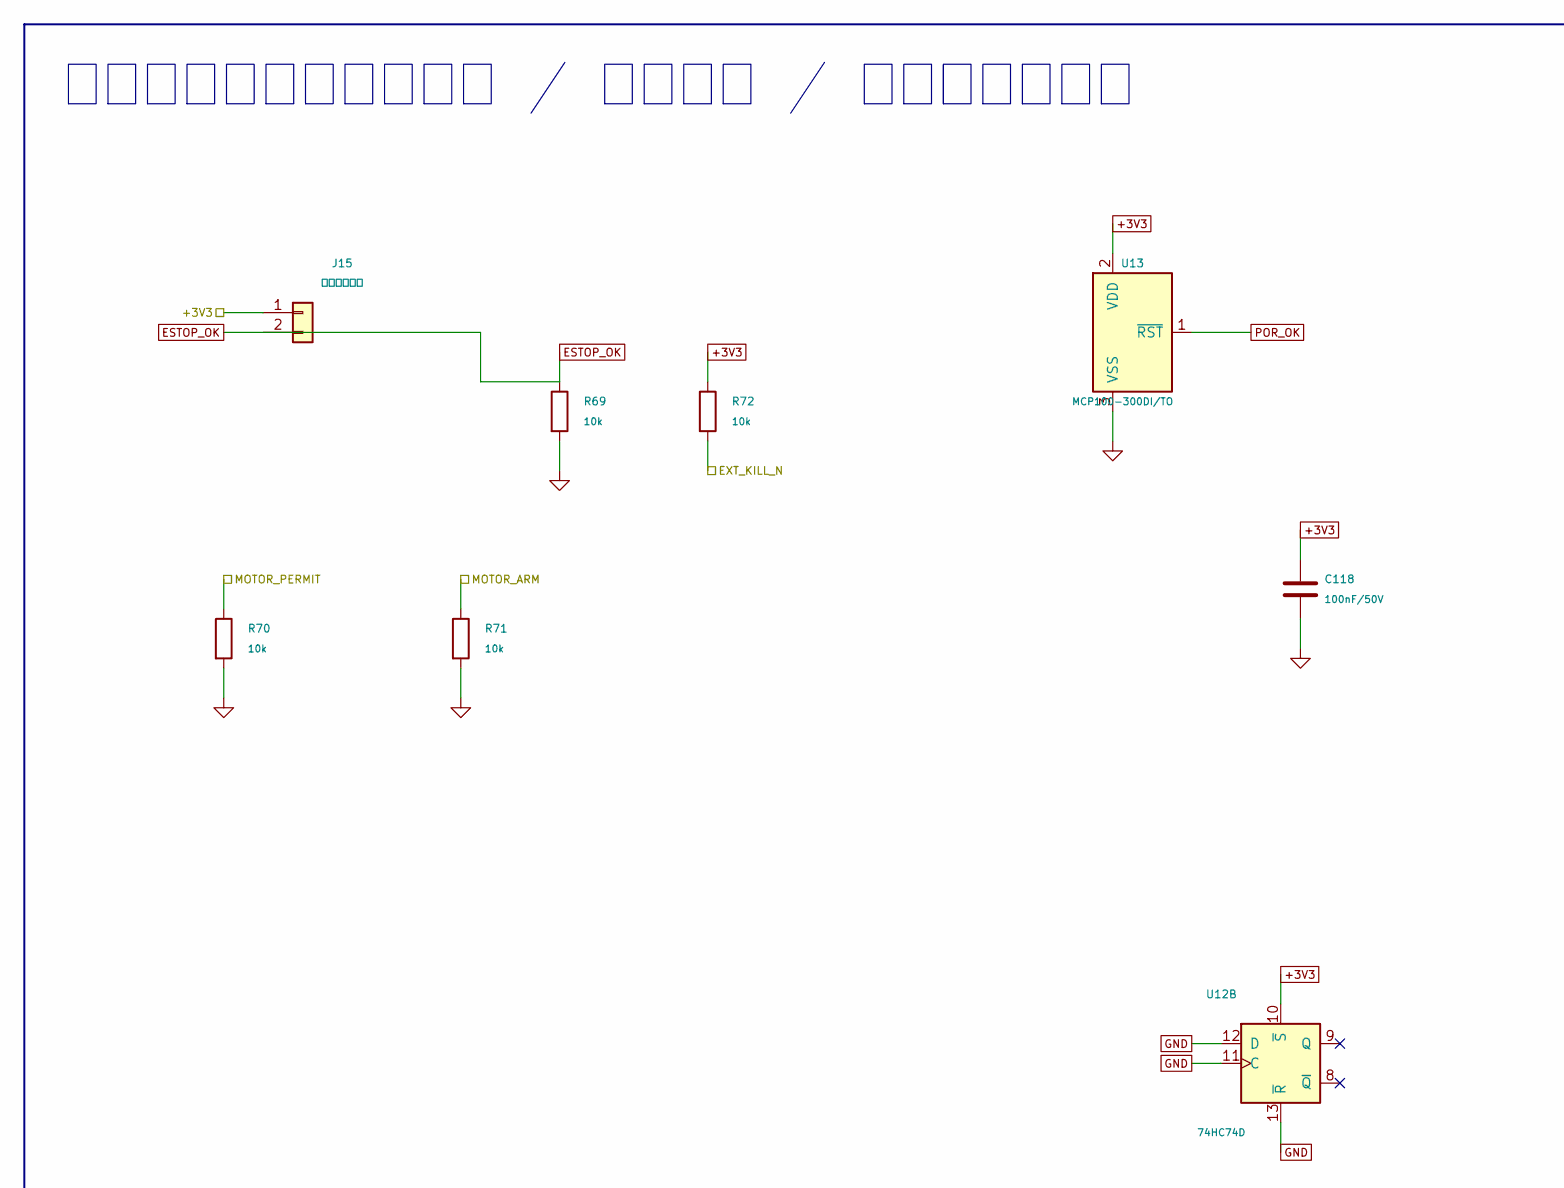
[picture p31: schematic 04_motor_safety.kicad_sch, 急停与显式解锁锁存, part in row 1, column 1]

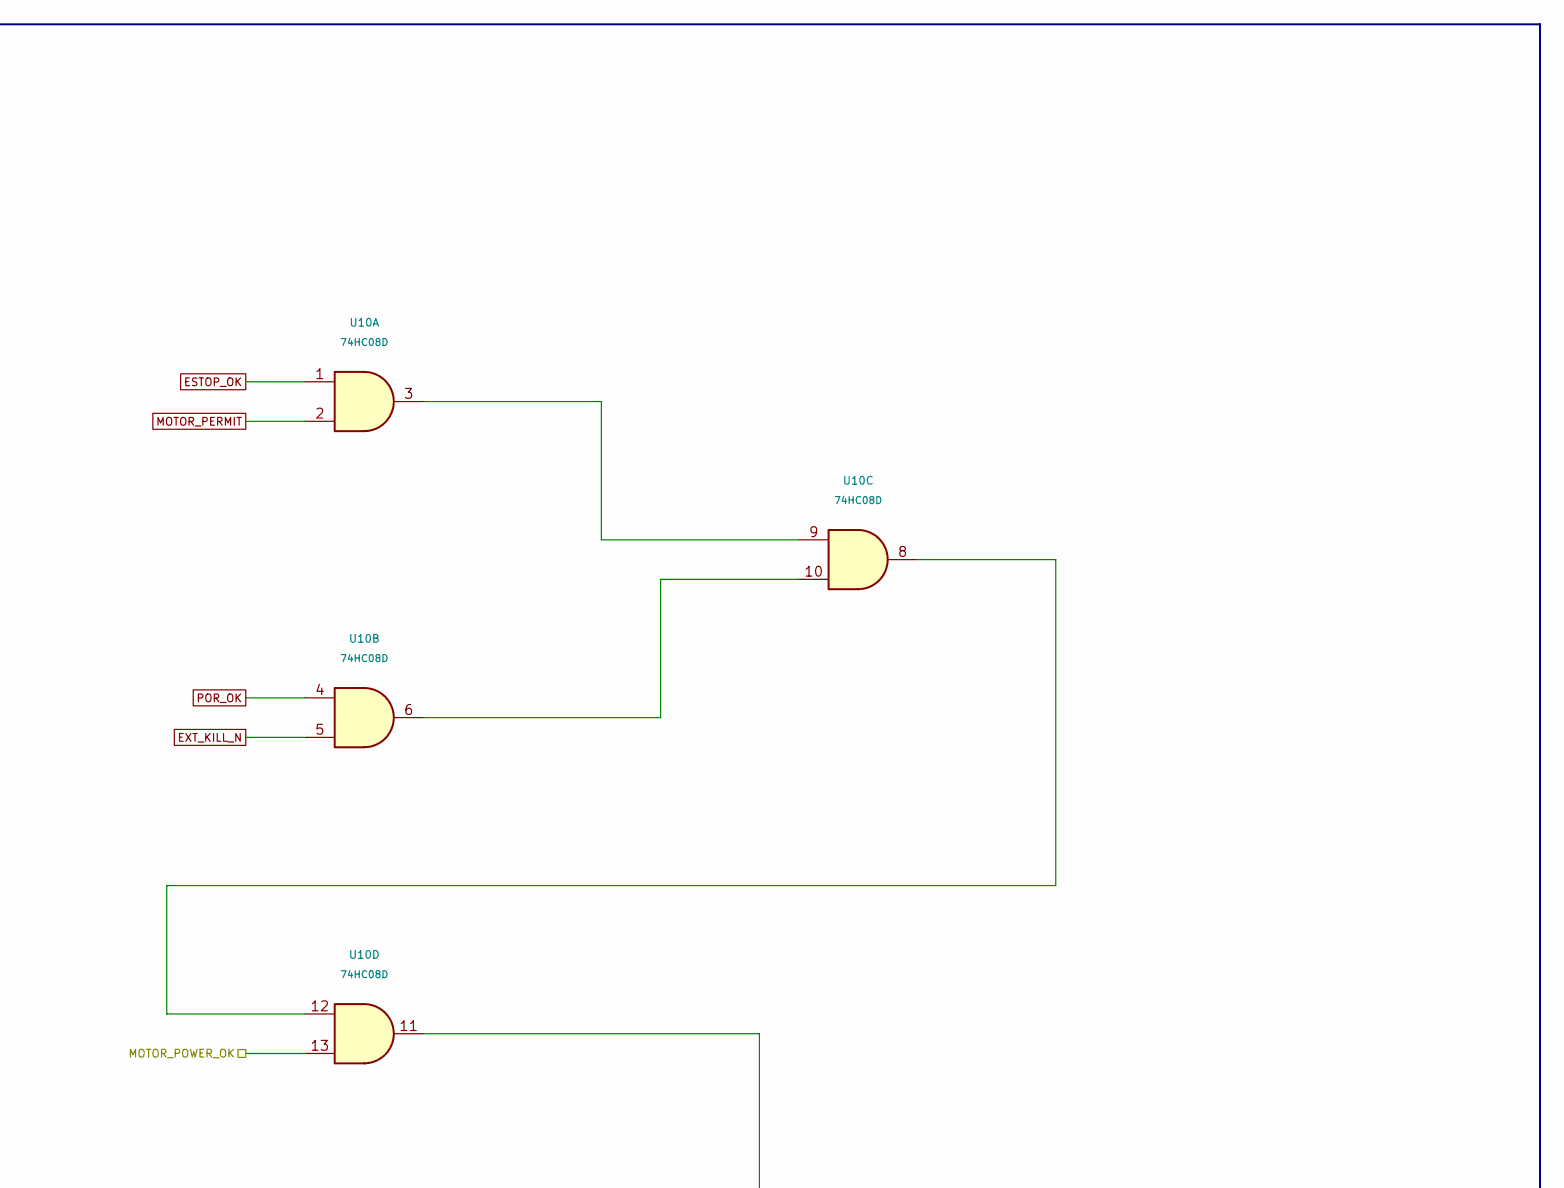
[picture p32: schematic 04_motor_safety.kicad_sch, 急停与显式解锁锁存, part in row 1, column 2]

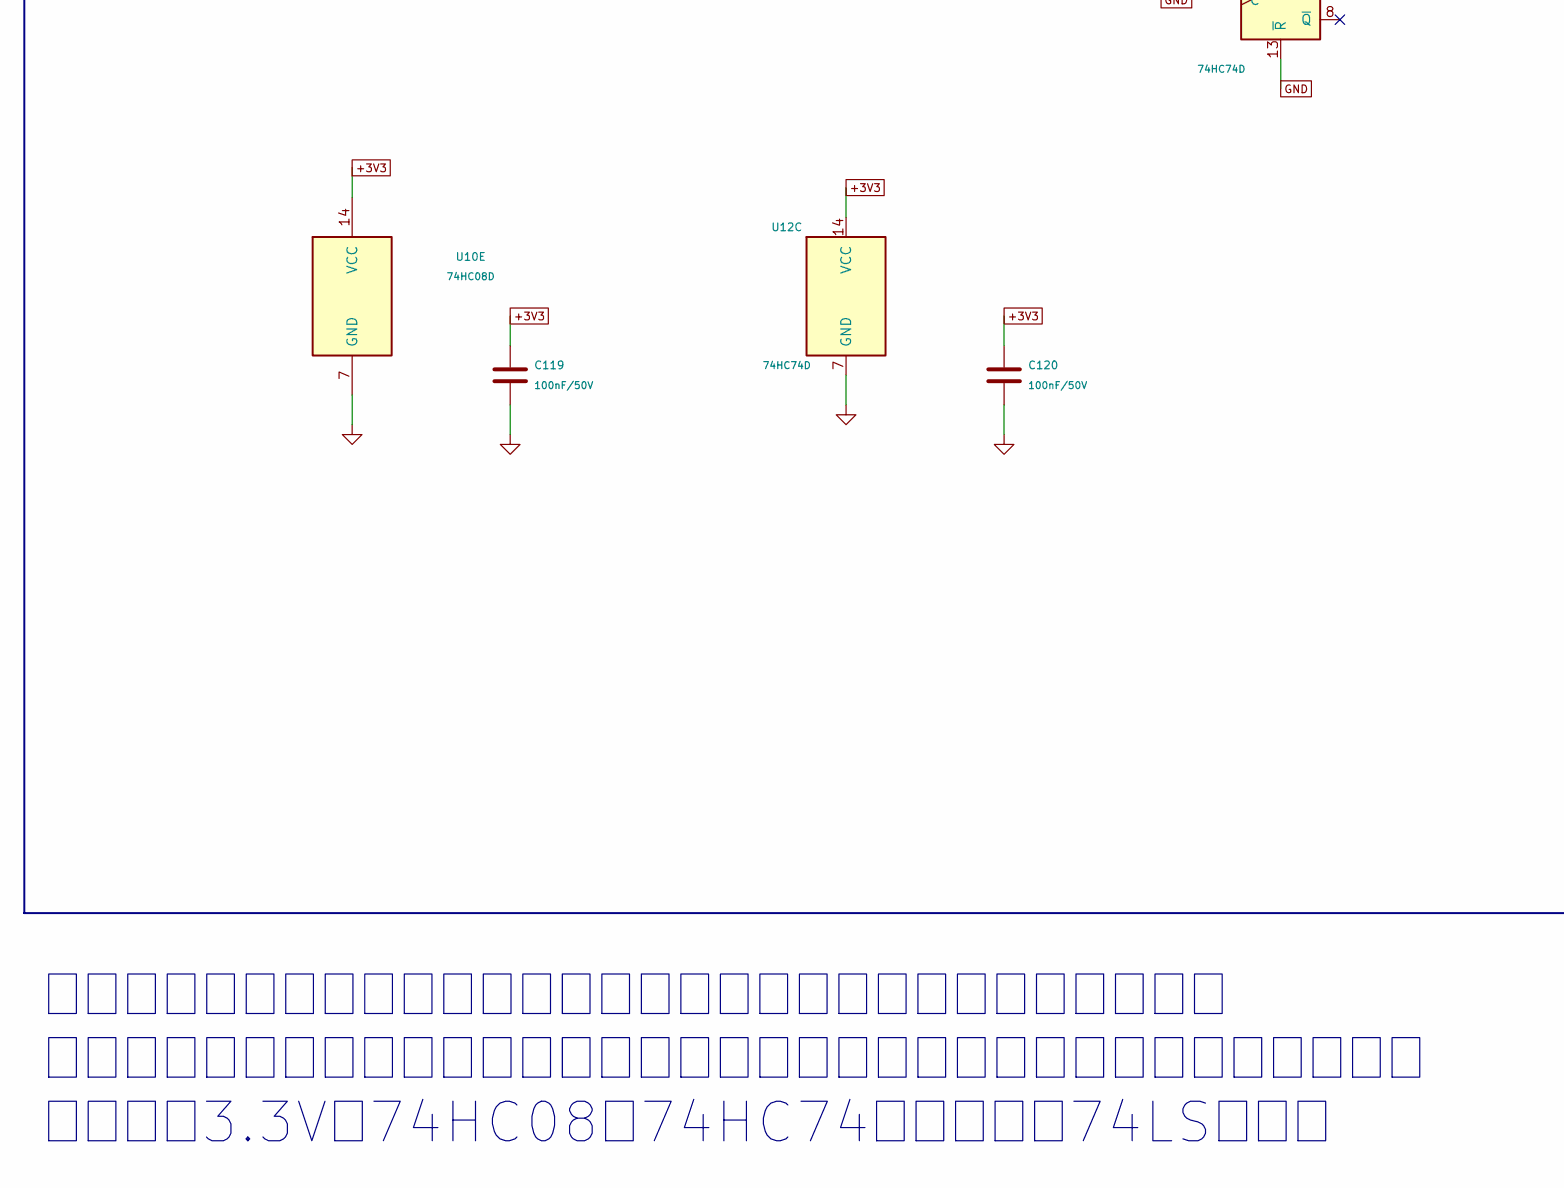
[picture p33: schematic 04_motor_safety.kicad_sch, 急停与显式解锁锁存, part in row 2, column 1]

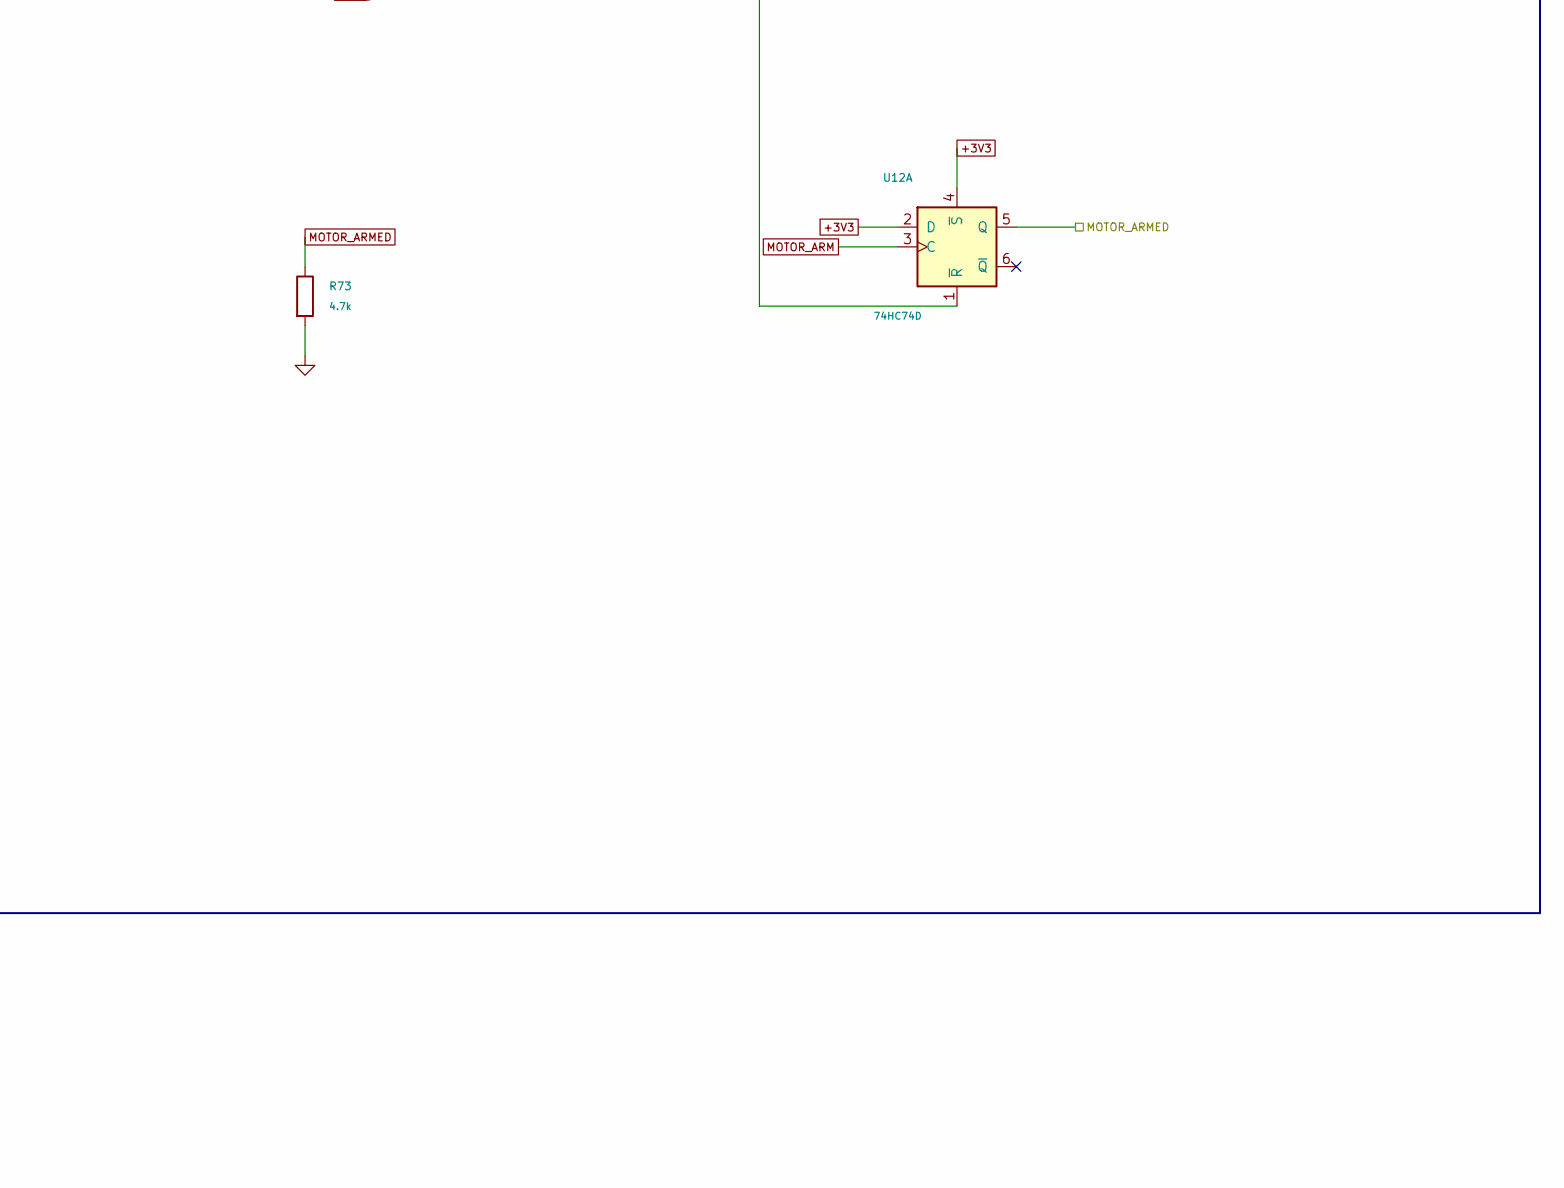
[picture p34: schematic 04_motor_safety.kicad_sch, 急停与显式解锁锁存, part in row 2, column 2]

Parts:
C118, C119, C120: 100nF/50V; C_0805_2012Metric
J15: 急停常闭回路; TerminalBlock_Phoenix_MKDS-1,5-2-5.08_1x02_P5.08mm_Horizont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
R69, R70, R71, R72: 10k; R_0603_1608Metric
R73: 4.7k; R_0603_1608Metric
U10: 74HC08D; SOIC-14_3.9x8.7mm_P1.27mm; MPN SN74HC08DR
U12: 74HC74D; SOIC-14_3.9x8.7mm_P1.27mm; MPN SN74HC74DR
U13: MCP100-300DI/TO; TO-92_Inline; MPN MCP100-300DI/TO

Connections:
+3V3: C118.1, C119.1, C120.1, J15.1, R72.1, U10.14 (VCC), U12.2 (D), U12.4 (~S), U12.10 (~S), U12.14 (VCC), U13.2 (VDD); also elsewhere on the board
ESTOP_OK: J15.2, R69.1, U10.1; also elsewhere on the board
EXT_KILL_N: R72.2, U10.5; also elsewhere on the board
GND: C118.2, C119.2, C120.2, R69.2, R70.2, R71.2, R73.2, U10.7 (GND), U12.7 (GND), U12.11 (C), U12.12 (D), U12.13 (~R), U13.3 (VSS); also elsewhere on the board
MOTOR_ARM: R71.1, U12.3 (C); also elsewhere on the board
MOTOR_ARMED: R73.1, U12.5 (Q); also elsewhere on the board
MOTOR_PERMIT: R70.1, U10.2; also elsewhere on the board
MOTOR_POWER_OK: U10.13; also elsewhere on the board
unnamed: U10.3, U10.9
unnamed: U10.6, U10.10
unnamed: U10.8, U10.12
unnamed: U10.11, U12.1 (~R)
POR_OK: U10.4, U13.1 (~RST); also elsewhere on the board

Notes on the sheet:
急停断开、运行许可撤销、外部故障、欠压或过流均立即清除解锁。 条件恢复后还须发出解锁脉冲；逻辑板须在看门狗超时或堵转时撤销运行许可。 使用支持3.3V的74HC08与74HC74，不可换成74LS系列。
动力硬件锁存：上电关闭 / 常闭急停 / 解锁需要上升沿

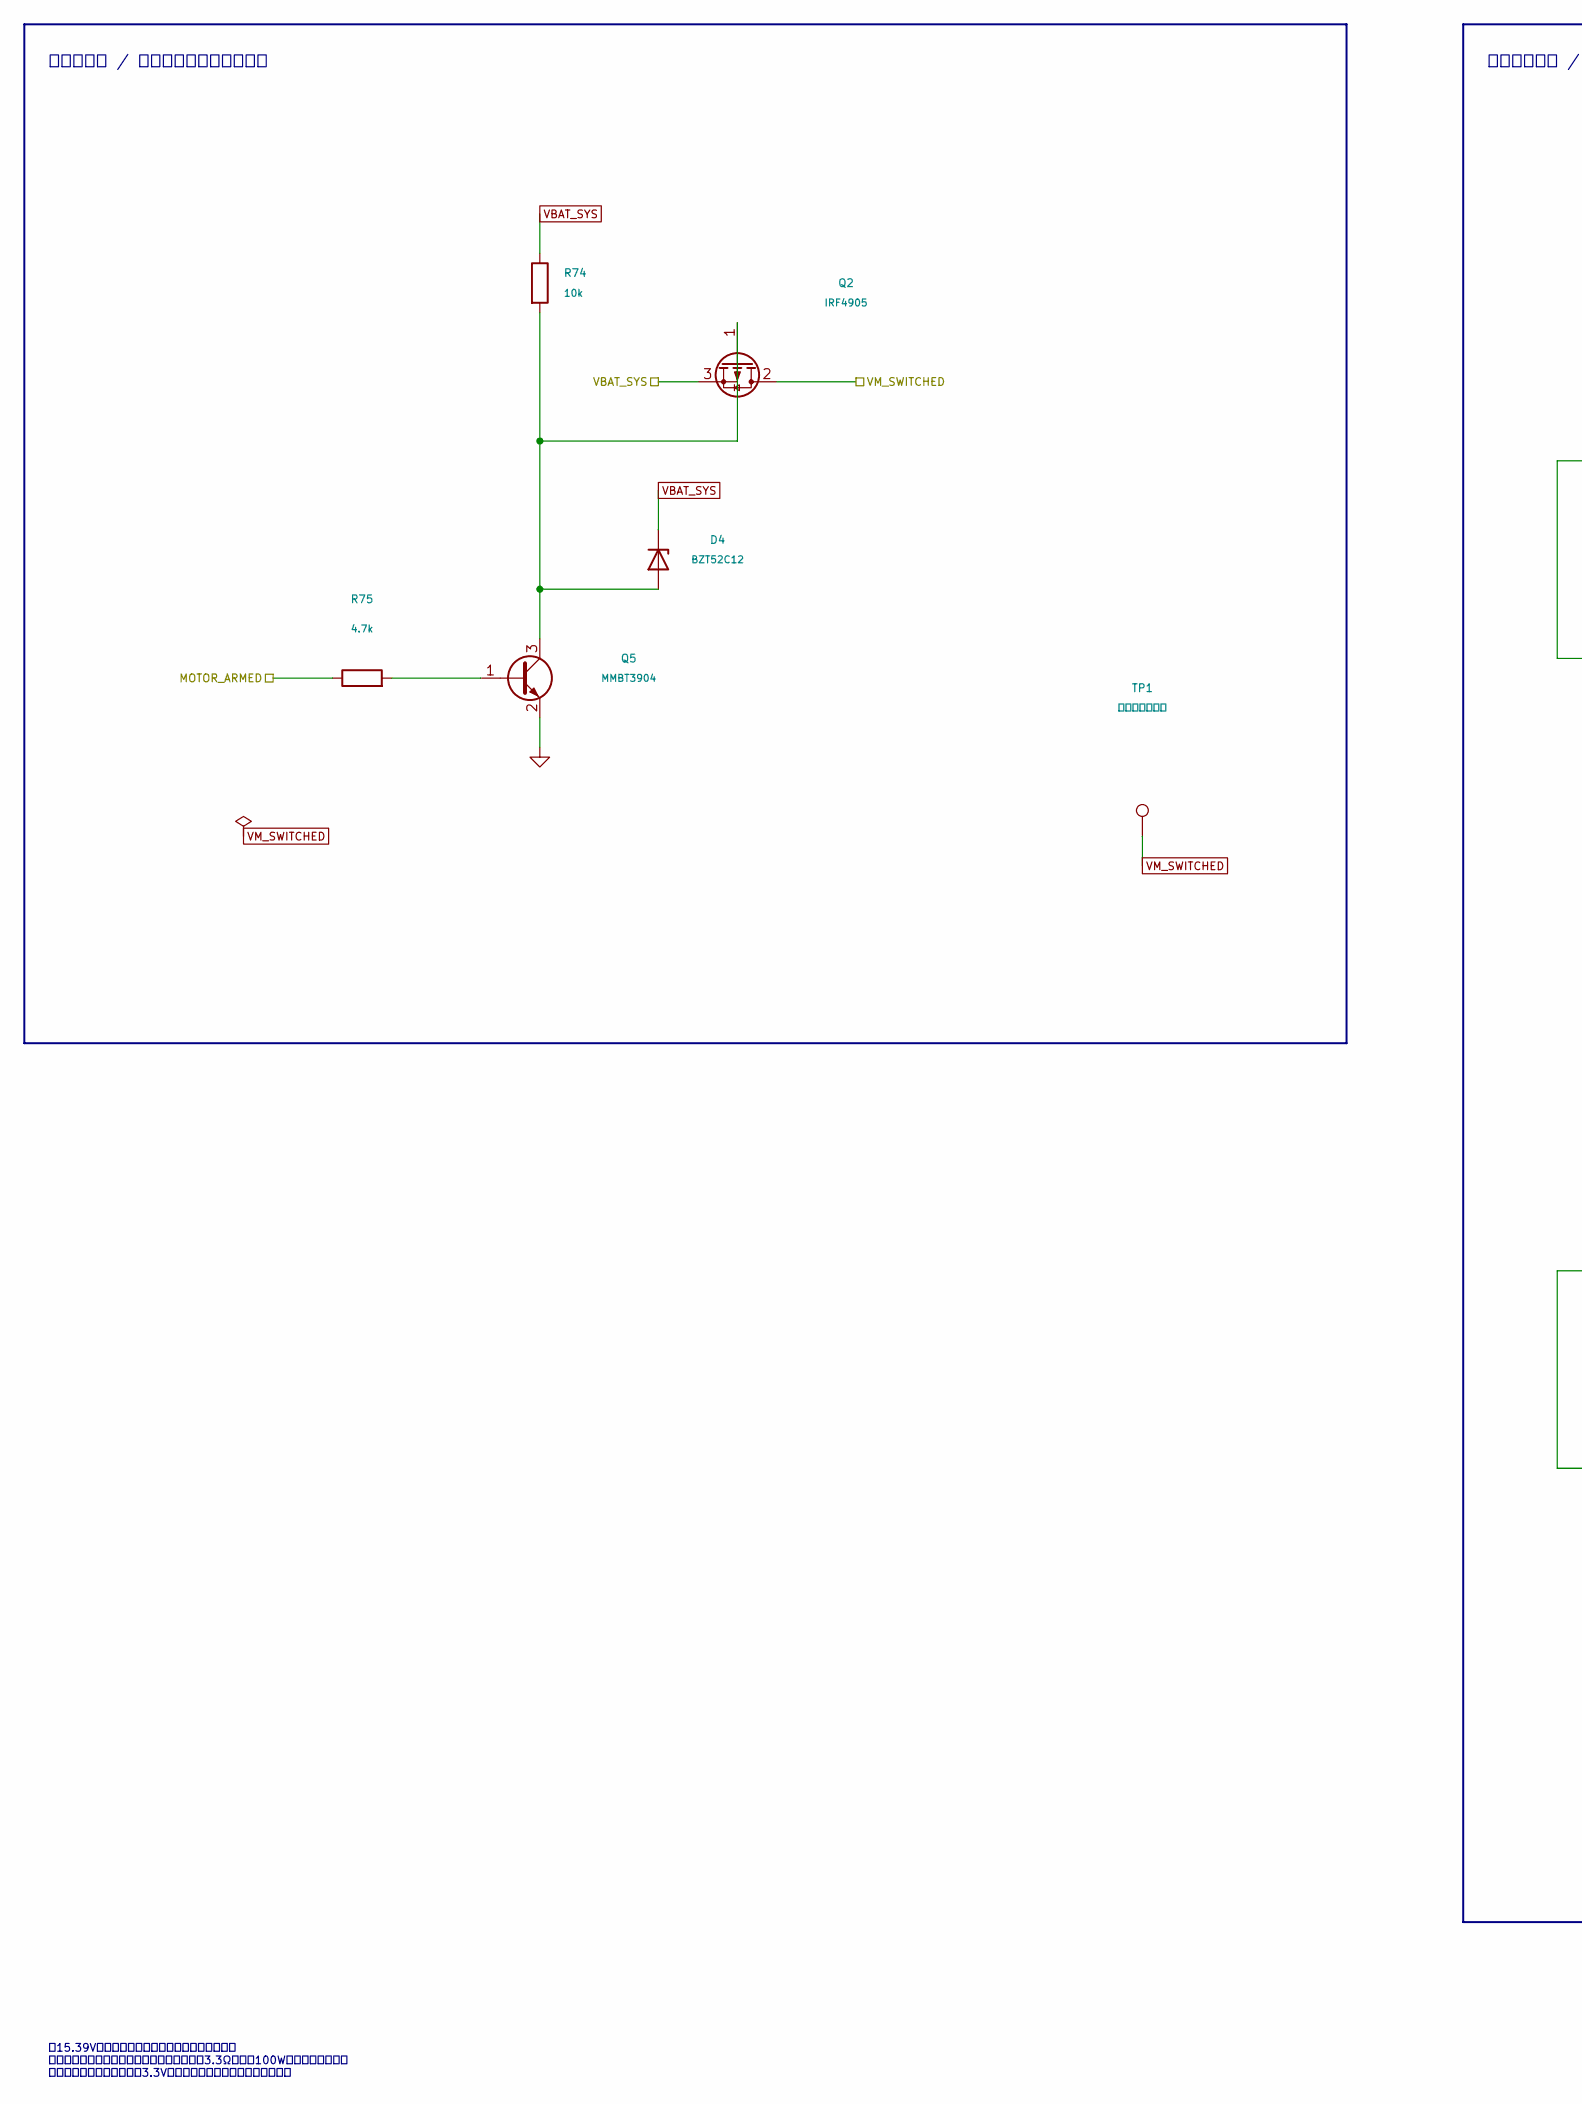
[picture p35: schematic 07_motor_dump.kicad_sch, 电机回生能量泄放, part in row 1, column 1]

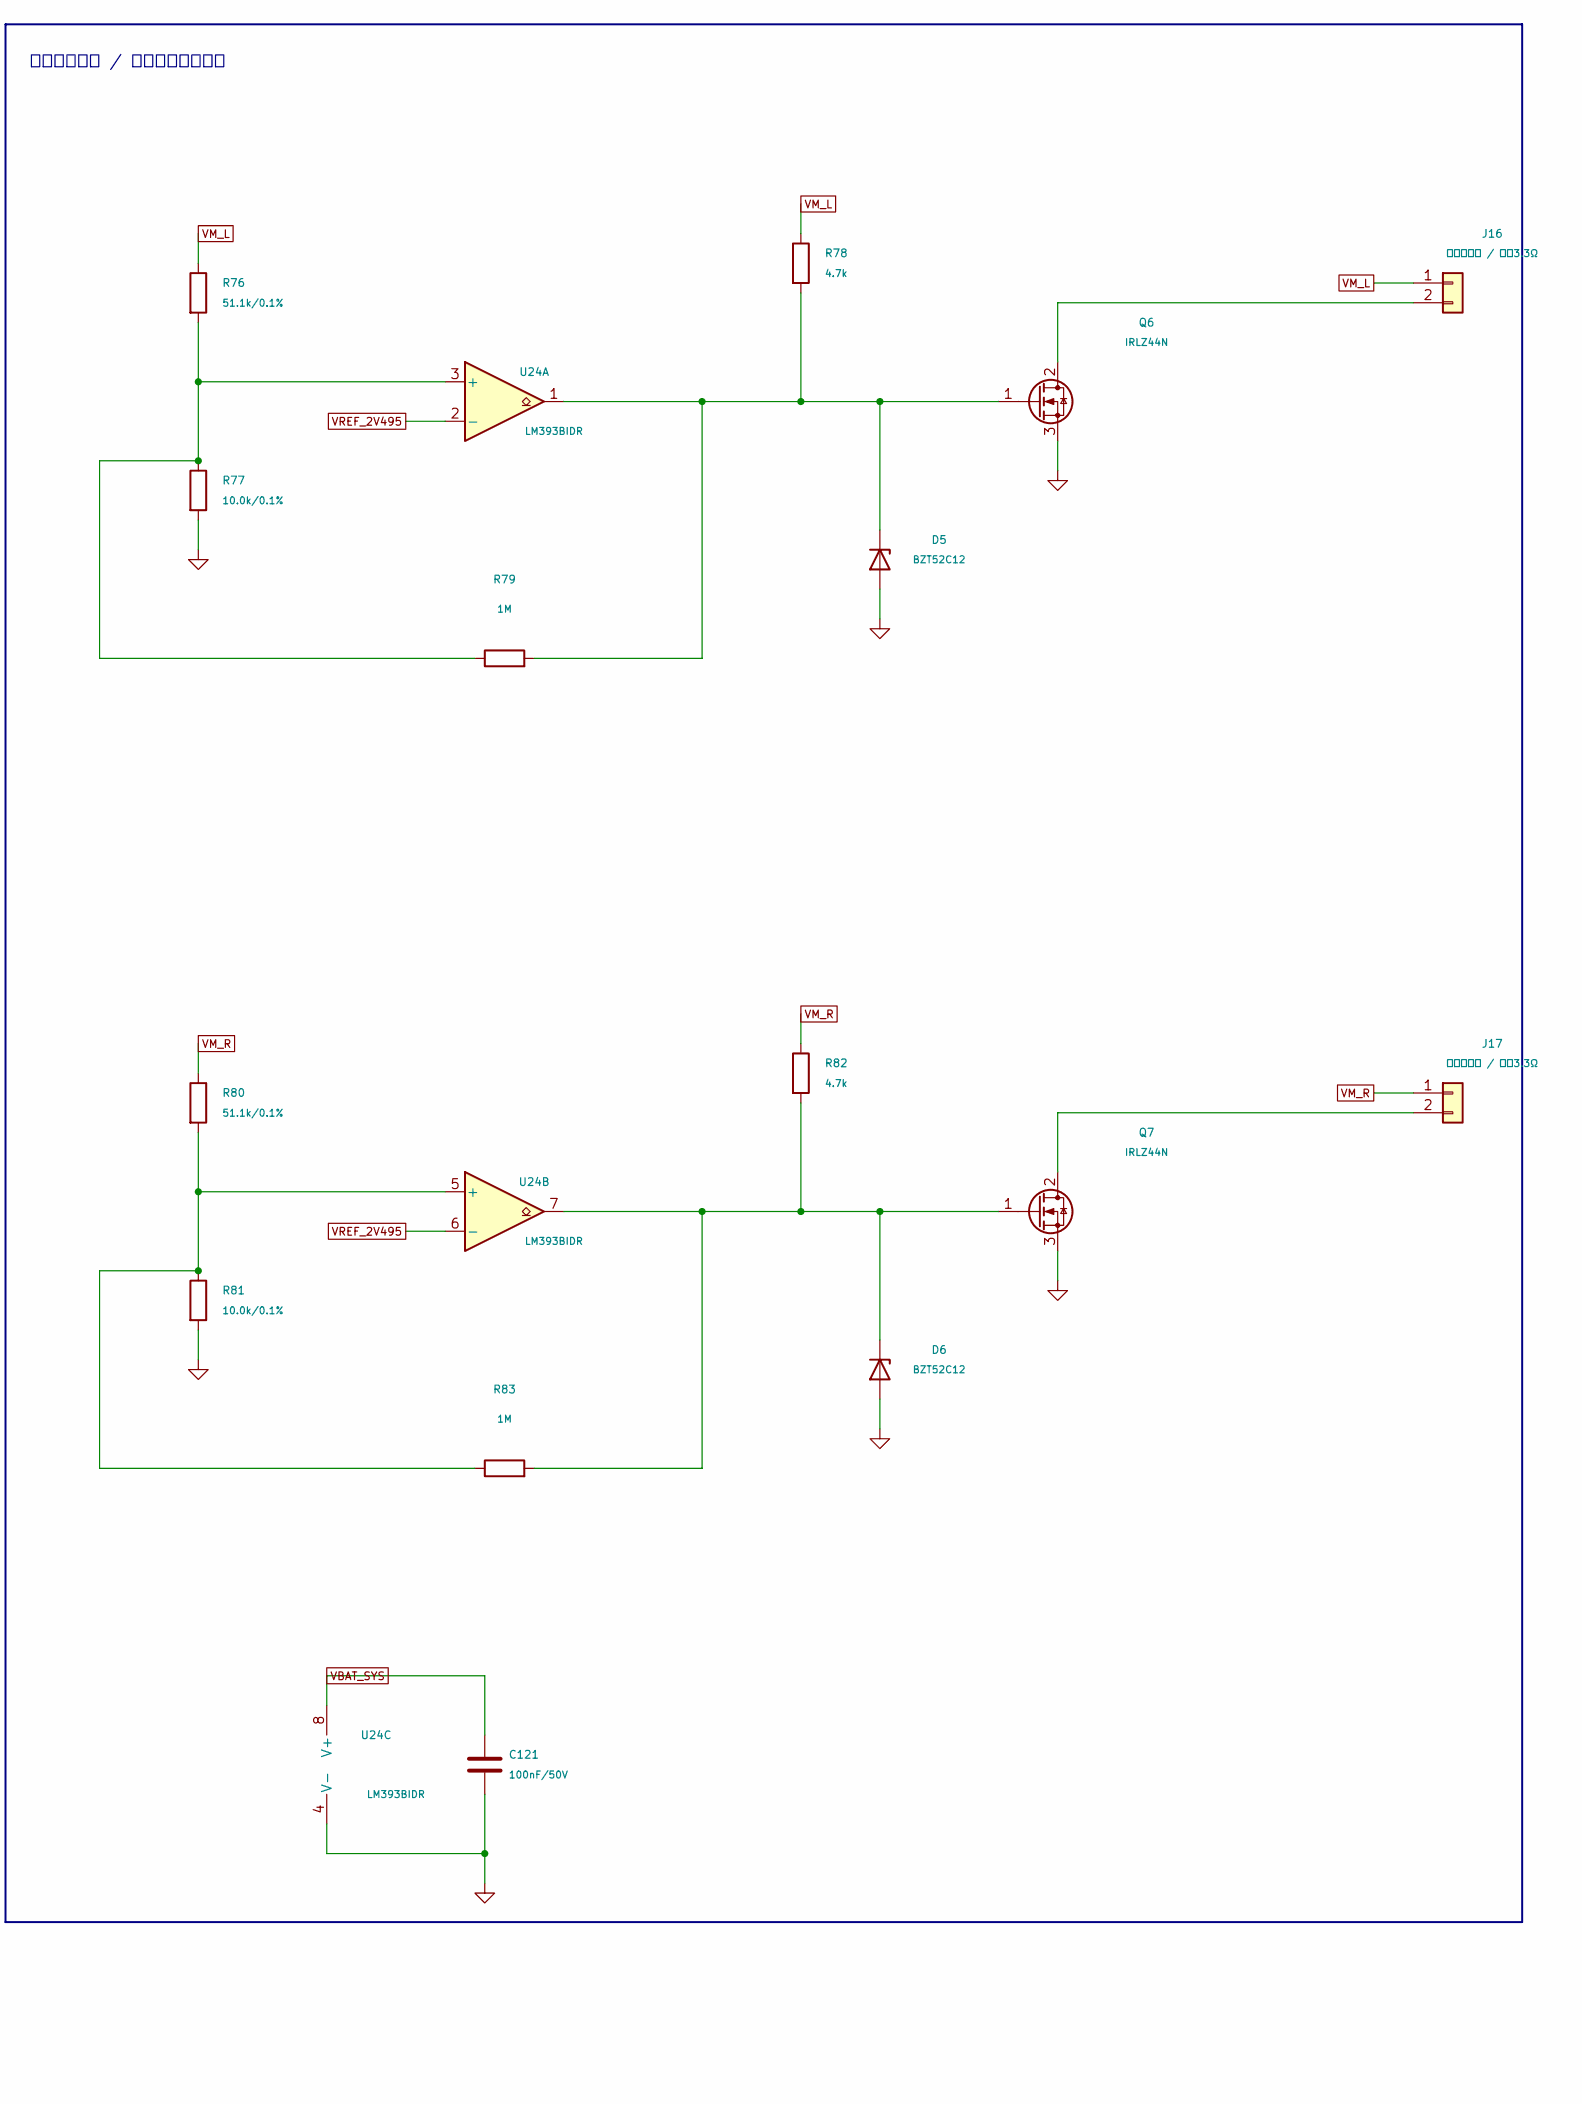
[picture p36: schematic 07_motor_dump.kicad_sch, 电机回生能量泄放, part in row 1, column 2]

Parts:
C121: 100nF/50V; C_0805_2012Metric
D4, D5, D6: BZT52C12; D_SOD-123
J16: 左回生泄放 / 外接3.3Ω; TerminalBlock_Phoenix_MKDS-1,5-2-5.08_1x02_P5.08mm_Horizont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
J17: 右回生泄放 / 外接3.3Ω; TerminalBlock_Phoenix_MKDS-1,5-2-5.08_1x02_P5.08mm_Horizont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
Q2: IRF4905; TO-220-3_Vertical; MPN IRF4905
Q5: MMBT3904; SOT-23; MPN MMBT3904
Q6, Q7: IRLZ44N; TO-220-3_Vertical; MPN IRLZ44N
R74: 10k; R_0603_1608Metric
R75, R78, R82: 4.7k; R_0603_1608Metric
R76, R80: 51.1k/0.1%; R_0603_1608Metric
R77, R81: 10.0k/0.1%; R_0603_1608Metric
R79, R83: 1M; R_0603_1608Metric
TP1: 电机总开关输出; TestPoint_Pad_D2.0mm
U24: LM393BIDR; SOIC-8_3.9x4.9mm_P1.27mm; MPN LM393BIDR

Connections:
GND: C121.2, D5.2 (A), D6.2 (A), Q5.2 (E), Q6.3 (S), Q7.3 (S), R77.2, R81.2, U24.4 (V-); also elsewhere on the board
MOTOR_ARMED: R75.1; also elsewhere on the board
unnamed: D4.2 (A), Q2.1 (G), Q5.3 (C), R74.2
unnamed: D5.1 (K), Q6.1 (G), R78.2, R79.2, U24.1
unnamed: D6.1 (K), Q7.1 (G), R82.2, R83.2, U24.7
unnamed: J16.2, Q6.2 (D)
unnamed: J17.2, Q7.2 (D)
unnamed: Q5.1 (B), R75.2
unnamed: R76.2, R77.1, R79.1, U24.3 (+)
unnamed: R80.2, R81.1, R83.1, U24.5 (+)
VBAT_SYS: C121.1, D4.1 (K), Q2.3 (S), R74.1, U24.8 (V+); also elsewhere on the board
VM_L: J16.1, R76.1, R78.1; also elsewhere on the board
VM_R: J17.1, R80.1, R82.1; also elsewhere on the board
VM_SWITCHED: Q2.2 (D), TP1.1 (1_1); also elsewhere on the board
VREF_2V495: U24.2 (-), U24.6 (-); also elsewhere on the board

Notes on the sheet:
回生能量泄放 / 外接底盘散热电阻
约15.39V开始泄放；关闭阈值和最坏过冲须实测。 若电源或电池保护板不能吸收回生，外接两只3.3Ω、至少100W的底盘散热电阻。 电路由电池母线供电，本板3.3V消失时仍可工作；功率管需要散热。
动力总开关 / 急停触点只承载控制电流

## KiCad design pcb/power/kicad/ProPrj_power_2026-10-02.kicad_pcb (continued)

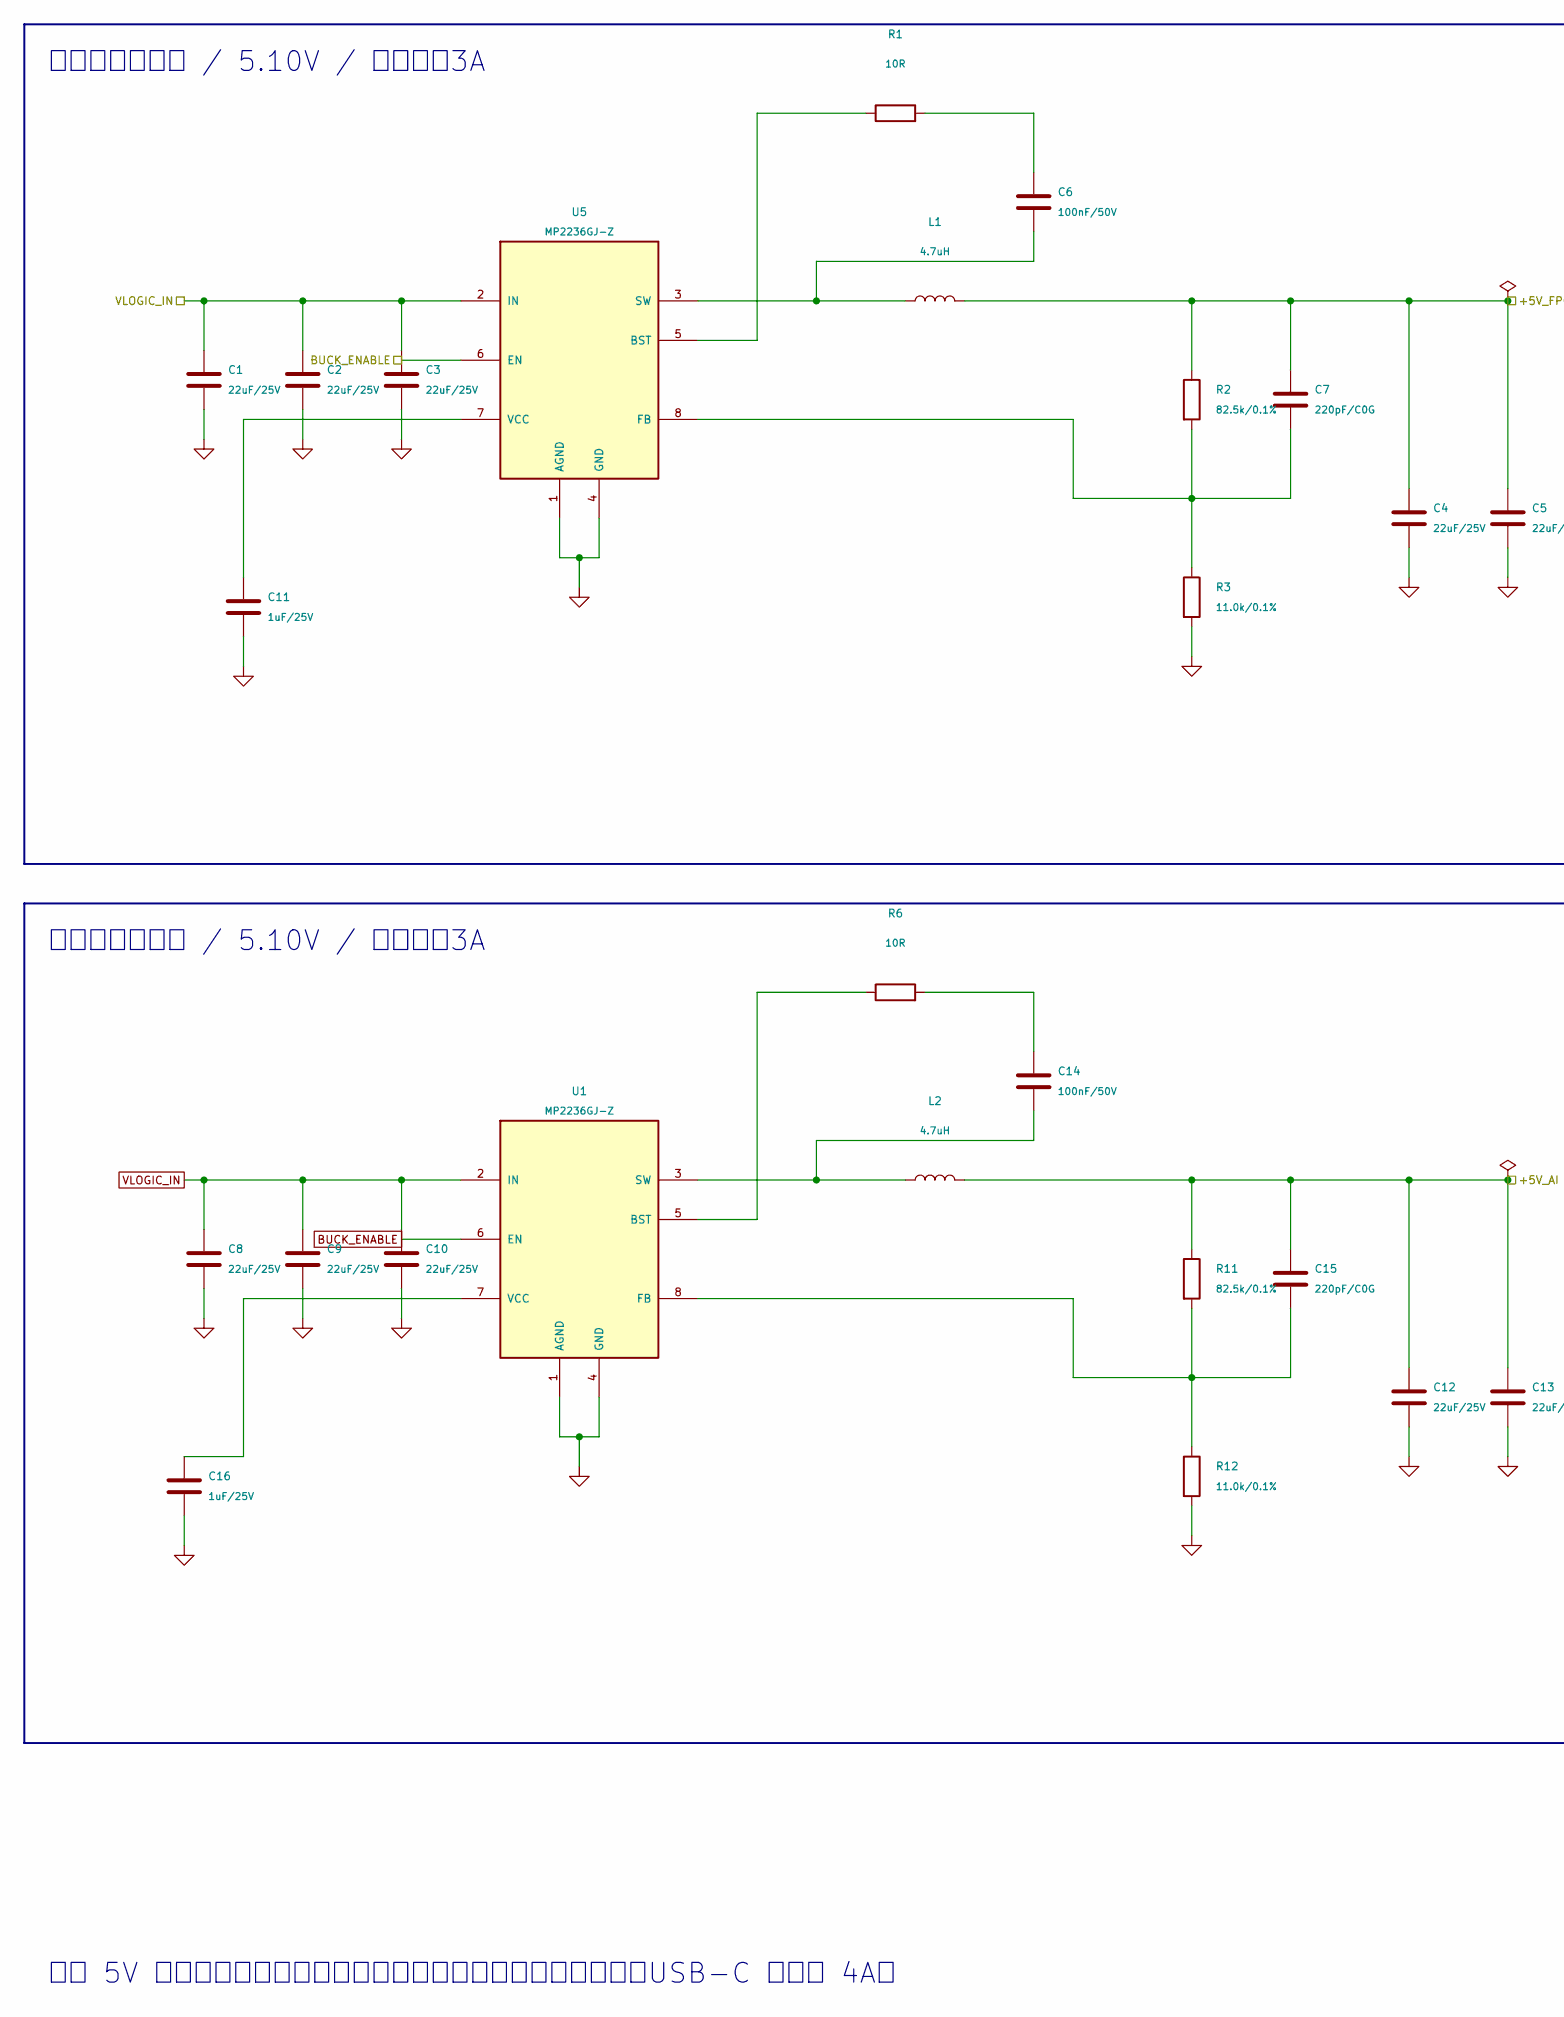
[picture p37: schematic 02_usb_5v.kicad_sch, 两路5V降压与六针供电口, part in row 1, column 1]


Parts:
C1, C2, C3, C4, C5, C8, C9, C10, C12, C13: 22uF/25V; C_0805_2012Metric
C6, C14: 100nF/50V; C_0603_1608Metric
C7, C15: 220pF/C0G; C_0603_1608Metric
C11, C16, C104, C106: 1uF/25V; C_0805_2012Metric
C105, C107: 4.7uF/10V; C_0805_2012Metric
L1, L2: 4.7uH; L_Changjiang_FXL0630; MPN FXL0630-4R7-M
R1, R6: 10R; R_0603_1608Metric
R2, R11: 82.5k/0.1%; R_0603_1608Metric
R3, R12: 11.0k/0.1%; R_0603_1608Metric
R65, R67: 150k/1%; R_0603_1608Metric
R66, R68: 10k; R_0603_1608Metric
U1, U5: MP2236GJ-Z; TSOT-23-8; MPN MP2236GJ-Z
U7, U8: HUSB305-02; TSOT-23-8; MPN HUSB305-02
USB1, USB2: USB4125-GF-A / 六针供电; USB_C_Receptacle_GCT_USB4125-xx-x_6P_TopMnt_Horizontal; MPN USB4125-GF-A

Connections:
+3V3: R66.1, R68.1; also elsewhere on the board
+5V_AI: C12.1, C13.1, C15.1, L2.2, R11.1; also elsewhere on the board
+5V_AI_PROT: C106.1, U8.1 (VIN); also elsewhere on the board
+5V_FPGA: C4.1, C5.1, C7.1, L1.2, R2.1; also elsewhere on the board
+5V_FPGA_PROT: C104.1, U7.1 (VIN); also elsewhere on the board
BUCK_ENABLE: U1.6 (EN), U5.6 (EN); also elsewhere on the board
GND: C1.2, C2.2, C3.2, C4.2, C5.2, C8.2, C9.2, C10.2, C11.2, C12.2, C13.2, C16.2, C104.2, C105.2, C106.2, C107.2, R3.2, R12.2, R65.2, R67.2, U1.1 (AGND), U1.4 (GND), U5.1 (AGND), U5.4 (GND), U7.2 (GND), U8.2 (GND), USB1.A12 (GND), USB1.B12 (GND), USB1.SH (SHIELD), USB2.A12 (GND), USB2.B12 (GND), USB2.SH (SHIELD); also elsewhere on the board
unnamed: C6.1, R1.2
unnamed: C14.1, R6.2
unnamed: R6.1, U1.5 (BST)
unnamed: C15.2, R11.2, R12.1, U1.8 (FB)
unnamed: C14.2, L2.1, U1.3 (SW)
unnamed: C16.1, U1.7 (VCC)
unnamed: R1.1, U5.5 (BST)
unnamed: C7.2, R2.2, R3.1, U5.8 (FB)
unnamed: C6.2, L1.1, U5.3 (SW)
unnamed: C11.1, U5.7 (VCC)
unnamed: U7.6 (CC1), USB1.A5 (CC1)
unnamed: U7.5 (CC2), USB1.B5 (CC2)
unnamed: R65.1, U7.3 (ISET)
unnamed: U8.6 (CC1), USB2.A5 (CC1)
unnamed: U8.5 (CC2), USB2.B5 (CC2)
unnamed: R67.1, U8.3 (ISET)
USB1_FAULT_PULSE_N: R66.2, U7.7 (STAT); also elsewhere on the board
USB1_VBUS: C105.1, U7.8 (VBUS), USB1.A9 (VBUS), USB1.B9 (VBUS)
USB2_FAULT_PULSE_N: R68.2, U8.7 (STAT); also elsewhere on the board
USB2_VBUS: C107.1, U8.8 (VBUS), USB2.A9 (VBUS), USB2.B9 (VBUS)
VLOGIC_IN: C1.1, C2.1, C3.1, C8.1, C9.1, C10.1, U1.2 (IN), U5.2 (IN); also elsewhere on the board

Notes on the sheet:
逻辑板降压输出 / 5.10V / 供电目标3A
USB2 / 六针供电口 / 固定5V
连接检测与总线电源开关由控制器完成 限流电阻150kΩ：典型限流3.6A，宣告供电能力3A 无需外部上拉电阻；仅固定5V供电
两路 5V 不并联。实际负载、板端电压、线缆压降和温升需实测；USB-C 不宣告 4A。
计算板降压输出 / 5.10V / 供电目标3A
USB1 / 六针供电口 / 固定5V



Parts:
C139, C140, C141, C142: 100nF/50V; C_0805_2012Metric
D7, D8: BZT52C12; D_SOD-123
Q8, Q10: AO4409; SOIC-8_3.9x4.9mm_P1.27mm; MPN AO4409
Q9, Q11, Q13: MMBT3904; SOT-23; MPN MMBT3904
Q12: AO3401A; SOT-23; MPN AO3401A
R104, R109: 11.5k/0.1%; R_0603_1608Metric
R105, R110, R115, R120, R123: 10.0k/0.1%; R_0603_1608Metric
R106, R111, R118, R121: 10k; R_0603_1608Metric
R107, R112, R116: 1k; R_0603_1608Metric
R108, R113, R117: 4.7k; R_0603_1608Metric
R114: 3.83k/0.1%; R_0603_1608Metric
R119: 30.9k/0.1%; R_0603_1608Metric
R122: 10.5k/0.1%; R_0603_1608Metric
U27, U28, U29, U30: LM393BIDR; SOIC-8_3.9x4.9mm_P1.27mm; MPN LM393BIDR

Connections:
3V3_ONBOARD_OK: R117.1, R118.2, U29.1
+3V3: R121.1; also elsewhere on the board
+3V3_ONBOARD: Q12.3 (D); also elsewhere on the board
+3V3_RAW: Q12.2 (S), R114.1, R116.2; also elsewhere on the board
+5V_AI: D8.1 (K), Q10.1 (S), Q10.2 (S), Q10.3 (S), R109.1, R112.1; also elsewhere on the board
+5V_AI_OK: R111.2, R113.1, U28.1
+5V_AI_PROT: Q10.5 (D), Q10.6 (D), Q10.7 (D), Q10.8 (D); also elsewhere on the board
+5V_FPGA: D7.1 (K), Q8.1 (S), Q8.2 (S), Q8.3 (S), R104.1, R107.1; also elsewhere on the board
+5V_FPGA_OK: R106.2, R108.1, U27.1
+5V_FPGA_PROT: Q8.5 (D), Q8.6 (D), Q8.7 (D), Q8.8 (D); also elsewhere on the board
BAT_WARN_N: R121.2, U29.7; also elsewhere on the board
CURRENT_REF_1V217: R122.2, R123.1, U30.3 (+), U30.5 (+)
GND: C139.2, C140.2, C141.2, C142.2, Q9.2 (E), Q11.2 (E), Q13.2 (E), R105.2, R110.2, R115.2, R120.2, R123.2, U27.4 (V-), U27.5 (+), U28.4 (V-), U28.5 (+), U29.4 (V-), U30.4 (V-); also elsewhere on the board
MOTOR_POWER_OK: U30.1, U30.7; also elsewhere on the board
unnamed: D7.2 (A), Q8.4 (G), Q9.3 (C), R107.2
unnamed: D8.2 (A), Q10.4 (G), Q11.3 (C), R112.2
unnamed: Q9.1 (B), R108.2
unnamed: Q11.1 (B), R113.2
unnamed: Q12.1 (G), Q13.3 (C), R116.1
unnamed: Q13.1 (B), R117.2
unnamed: R104.2, R105.1, U27.2 (-)
unnamed: R109.2, R110.1, U28.2 (-)
unnamed: R114.2, R115.1, U29.2 (-)
unnamed: R119.2, R120.1, U29.5 (+)
VBAT_SYS: C139.1, C140.1, C141.1, C142.1, R106.1, R111.1, R118.1, R119.1, U27.8 (V+), U28.8 (V+), U29.8 (V+), U30.8 (V+); also elsewhere on the board
VM_L_IMON: U30.2 (-); also elsewhere on the board
VM_R_IMON: U30.6 (-); also elsewhere on the board
VREF_2V495: R122.1, U27.3 (+), U27.6 (-), U28.3 (+), U28.6 (-), U29.3 (+), U29.6 (-); also elsewhere on the board

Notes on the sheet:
逻辑板供电过压关断 / 标称约5.364V
板载3.3V过压关断 / 标称约3.451V
动力过流检测 / 滤波后母线电流 / 共用锁存清除
计算板供电过压关断 / 标称约5.364V
分立过压关断方案用于控制成本；故障阶跃过冲和温升须实测。 本方案不保证所有状态下阻断反灌，接入板卡仍须核对电源选择与隔离。 母线过流阈值标称约3.04A；入口总保险板载，电池单体保护和模块限流仍须落实。

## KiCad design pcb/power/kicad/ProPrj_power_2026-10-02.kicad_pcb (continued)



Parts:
C58: 470uF/35V; CP_Radial_D10.0mm_P5.00mm
C59: 10uF/50V; C_0805_2012Metric
C60, C102, C103: 100nF/50V; C_0805_2012Metric
C101: 100uF/25V; CP_Radial_D10.0mm_P5.00mm
CN1: XT60PW-M / 三串电池; AMASS_XT60PW-M_1x02_P7.20mm_Horizontal
D1: SMBJ15CA; D_SMB; MPN SMBJ15CA
D2, D3: BZT52C12; D_SOD-123
F1: 10A/32V MINI总保险; Fuseholder_Blade_Mini_Keystone_3568; MPN 0297010.J
Q1, Q3: IRF4905; TO-220-3_Vertical; MPN IRF4905
Q4: MMBT3904; SOT-23; MPN MMBT3904
R51: 100k; R_0603_1608Metric
R52: 2.2k; R_0603_1608Metric
R53, R59, R64: 10k; R_0603_1608Metric
R54: 4.7k; R_0603_1608Metric
R55: 26.1k/0.1%; R_0603_1608Metric
R56, R58, R61, R63: 10.0k/0.1%; R_0603_1608Metric
R57, R62: 46.4k/0.1%; R_0603_1608Metric
R60: 28.7k/0.1%; R_0603_1608Metric
U21: TL431BIDBZR; SOT-23; MPN TL431BIDBZR
U22, U23: LM393BIDR; SOIC-8_3.9x4.9mm_P1.27mm; MPN LM393BIDR

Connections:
+3V3: R64.1; also elsewhere on the board
BAT_POS: CN1.2, F1.1
BUCK_ENABLE: R54.1, R59.2, U22.1, U22.7; also elsewhere on the board
GND: C58.2, C59.2, C60.2, C101.2, C102.2, C103.2, CN1.1, D1.2 (A2), Q4.2 (E), R51.2, R56.2, R58.2, R61.2, R63.2, U21.3 (A), U22.4 (V-), U23.4 (V-); also elsewhere on the board
MOTOR_POWER_OK: R64.2, U23.1, U23.7; also elsewhere on the board
unnamed: D2.2 (A), Q1.1 (G), R51.1
unnamed: D3.2 (A), Q3.1 (G), Q4.3 (C), R53.2
unnamed: F1.2, Q1.2 (D)
unnamed: Q4.1 (B), R54.2
unnamed: R55.2, R56.1, U22.3 (+)
unnamed: R57.2, R58.1, U22.6 (-)
unnamed: R60.2, R61.1, U23.3 (+)
unnamed: R62.2, R63.1, U23.6 (-)
VBAT_SYS: C58.1, C59.1, C60.1, C102.1, C103.1, D1.1 (A1), D2.1 (K), D3.1 (K), Q1.3 (S), Q3.3 (S), R52.1, R53.1, R55.1, R57.1, R59.1, R60.1, R62.1, U22.8 (V+), U23.8 (V+); also elsewhere on the board
VLOGIC_IN: C101.1, Q3.2 (D); also elsewhere on the board
VREF_2V495: R52.2, U21.1 (K), U21.2 (REF), U22.2 (-), U22.5 (+), U23.2 (-), U23.5 (+); also elsewhere on the board

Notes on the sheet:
电池母线基准与降压输入开关
欠压与过压窗口：逻辑约9.0-14.1V；动力约9.65-14.1V
输入：三串11.1V锂聚合物电池 / 板载总保险与防反接
开集电极故障输出共同拉低使能。电机故障清除解锁锁存；电压恢复后不自动解锁。 总电压监测不能替代单体电芯保护。阈值、响应和过冲须实测。
电池：11.1V / 3600mAh / 35C；满电12.6V。 F1板载：XT60正极之后、防反接管之前。 保险片：集电通0297010.J，10A/32V，初值待实测。 保险座：四孔9.92×3.40mm；与保险片分别采购。 照片不能确认电池保护板；单体电芯保护仍须落实。 瞬态抑制二极管不能把电压固定在17V以下。

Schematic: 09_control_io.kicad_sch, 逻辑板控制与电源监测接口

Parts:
C143: 100nF/25V; C_0603_1608Metric
J1: 左轮控制; PinHeader_1x08_P2.54mm_Vertical
J2: 右轮控制; PinHeader_1x08_P2.54mm_Vertical
J18: 电源监测 / 外部模数转换; PinHeader_1x12_P2.54mm_Vertical
R124: 100k/0.1%; R_0603_1608Metric
R125: 27.4k/0.1%; R_0603_1608Metric

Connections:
3V3_FPGA_IN: J1.6, J2.3; also elsewhere on the board
+3V3: J18.1; also elsewhere on the board
BAT_ADC: C143.1, J18.3, R124.2, R125.1
BAT_WARN_N: J18.4; also elsewhere on the board
ENC_L_A_FPGA: J1.7; also elsewhere on the board
ENC_L_B_FPGA: J1.8; also elsewhere on the board
ENC_R_A_FPGA: J2.2; also elsewhere on the board
ENC_R_B_FPGA: J2.1; also elsewhere on the board
ESTOP_OK: J18.11; also elsewhere on the board
EXT_KILL_N: J2.7; also elsewhere on the board
GND: C143.2, J1.5, J2.4, J18.2, R125.2; also elsewhere on the board
L_PWM_FWD_RAW: J1.1; also elsewhere on the board
L_PWM_REV_RAW: J1.2; also elsewhere on the board
MOTOR_ARM: J1.3; also elsewhere on the board
MOTOR_ARMED: J2.8, J18.8; also elsewhere on the board
MOTOR_PERMIT: J1.4; also elsewhere on the board
MOTOR_POWER_OK: J18.7; also elsewhere on the board
POR_OK: J18.12; also elsewhere on the board
R_PWM_FWD_RAW: J2.5; also elsewhere on the board
R_PWM_REV_RAW: J2.6; also elsewhere on the board
USB1_FAULT_PULSE_N: J18.9; also elsewhere on the board
USB2_FAULT_PULSE_N: J18.10; also elsewhere on the board
VBAT_SYS: R124.1; also elsewhere on the board
VM_L_IMON: J18.5; also elsewhere on the board
VM_R_IMON: J18.6; also elsewhere on the board

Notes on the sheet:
电池采样：12.6V对应约2.71V，需要外部模数转换器。 J1第6脚与J2第3脚均为逻辑板3.3V输入， 默认与本板输出隔离，只接同一个电源域。 复位或看门狗超时时，运行许可必须为低。 安全检查后，以解锁脉冲的上升沿解锁。 外部故障脚接受开漏低电平。 荔枝派普通输入输出需要合适的电平转换。
控制接口 / 电源方向 / 互斥电源选择
PCB封装与网络已同步，布局布线待完成。 仍须核对模块采样电阻、编码器版本与逻辑板供电接口。

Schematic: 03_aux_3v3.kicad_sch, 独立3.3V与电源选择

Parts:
C108: 10uF/25V; C_0805_2012Metric
C109: 100nF/50V; C_0603_1608Metric
C110, C111: 22uF/10V; C_0805_2012Metric
C112: 10uF/10V; C_0805_2012Metric
C113, C114, C115, C116, C117: 100nF/50V; C_0805_2012Metric
FB1: 220Ω@100MHz / 1A; L_0805_2012Metric
J9: 可选逻辑板3.3V输入; PinHeader_1x02_P2.54mm_Vertical
J10: 惯性传感器电源; JST_PH_B2B-PH-K_1x02_P2.00mm_Vertical
J11: 测距传感器1电源; JST_PH_B2B-PH-K_1x02_P2.00mm_Vertical
J12: 测距传感器2电源; JST_PH_B2B-PH-K_1x02_P2.00mm_Vertical
J13: 测距传感器3电源; JST_PH_B2B-PH-K_1x02_P2.00mm_Vertical
J14: 3.3V辅助输出; TerminalBlock_Phoenix_MKDS-1,5-2-5.08_1x02_P5.08mm_Horizont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
JP1: 1-2板载 / 2-3逻辑板; PinHeader_1x03_P2.54mm_Vertical
L3: 4.7uH; L_Changjiang_FXL0630; MPN FXL0630-4R7-M
U3: AP63203WU-7; TSOT-23-6; MPN AP63203WU-7

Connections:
3V3_FPGA_IN: J9.1, JP1.3; also elsewhere on the board
+3V3: FB1.1, J14.1, JP1.2; also elsewhere on the board
+3V3_ONBOARD: JP1.1; also elsewhere on the board
+3V3_RAW: C110.1, C111.1, L3.2, U3.1 (FB); also elsewhere on the board
+3V3_SENS: C112.1, C113.1, C114.1, C115.1, C116.1, C117.1, FB1.2, J10.1, J11.1, J12.1, J13.1; also elsewhere on the board
BUCK_ENABLE: U3.2 (EN); also elsewhere on the board
GND: C108.2, C110.2, C111.2, C112.2, C113.2, C114.2, C115.2, C116.2, C117.2, J9.2, J10.2, J11.2, J12.2, J13.2, J14.2, U3.4 (GND); also elsewhere on the board
unnamed: C109.2, U3.6 (BST)
unnamed: C109.1, L3.1, U3.5 (SW)
VLOGIC_IN: C108.1, U3.3 (IN); also elsewhere on the board

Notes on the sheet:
默认独立3.3V降压 / 初始负载预算0.5A
传感器电源滤波 / 仅接已确认支持3.3V的成品模块
芯片标称2A能力不能代替接口与散热验收。 反馈取自保护开关前的稳压输出。 4.7µH位于手册允许的2.2-10µH范围内。
默认短接1-2：板载3.3V供电。 确认逻辑板电流余量后，才能改为2-3。 只能装一个跳帽，不能并联两个电源。 默认安装板载降压电路。
本板3.3V供给编码器、电流监测和安全逻辑；传感器信号接逻辑板。 裸芯片与成品模块的供电要求可能不同，须核对实际模块。
JP1电源选择：只安装一个跳帽


Board: 2 copper layers, 211 parts (0 on the bottom side), 111 nets.

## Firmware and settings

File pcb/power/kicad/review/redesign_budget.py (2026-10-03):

"""Current R2: independent 3V3 by default, two 5V rails, 6P USB-C.

The existing PCB is read only. All physical packages are KiCad stock except
the two AT8236 socket carriers. Run this builder, then validate the native netlist.
"""
import redesign_schematic as g
from redesign_schematic import *
from kicad_tools import apply_edits

INDUCTOR='Inductor_SMD:L_Changjiang_FXL0630'
USB6='Connector_USB:USB_C_Receptacle_GCT_USB4125-xx-x_6P_TopMnt_Horizontal'
HUSB_DS='https://www.hynetek.com/uploadfiles/site/219/news/2a2293ad-5b62-48ab-b902-a09e7bf50a18.pdf'

def define_parts():
    g.CUSTOM.pop('EdgeMind_Power:TPS25940L',None)
    custom_symbol('HUSB305_02','U',[
      ('1','VIN','power_in',-15.24,7.62,0),('3','ISET','passive',-15.24,-7.62,0),
      ('4','NC','no_connect',-15.24,-12.7,0),('2','GND','power_in',0,-20.32,90),
      ('8','VBUS','power_out',15.24,7.62,180),('6','CC1','bidirectional',15.24,0,180),
      ('5','CC2','bidirectional',15.24,-5.08,180),('7','STAT','open_collector',15.24,-12.7,180)],
      description='Fixed 5V USB-C source; integrated attach detection, current limit and switched VBUS. STAT pulses on faults in -02 version.',
      fp='Package_TO_SOT_SMD:TSOT-23-8',datasheet=HUSB_DS)
    custom_symbol('AO4409','Q',[
      ('4','G','input',-10.16,0,0),
      *[(str(k),'S','passive',0,12.7,270) for k in [1,2,3]],
      *[(str(k),'D','passive',10.16,0,180) for k in [5,6,7,8]]],
      box=(-5.08,7.62,5.08,-7.62),description='30V P-channel MOSFET; SO8 pin4 G, pins1/2/3 S, pins5/6/7/8 D',fp=SO8,
      datasheet='https://www.aosmd.com/sites/default/files/res/datasheets/AO4409.pdf')
    # Stock quad AND drawing / pin numbers; explicitly CMOS HC rather than LS TTL.
    body=cached('74xx:74LS08').replace('74xx:74LS08','74HC08').replace('74LS08','74HC08')
    g.CUSTOM['EdgeMind_Power:74HC08']=body

def cmp_power(p,ref,x,y):
    u=p.sym('Comparator:LM393',ref,x,y,'LM393BIDR',SO8,unit=3,mpn='LM393BIDR')
    cc=C(p,x+17.78,y,'100nF 50V',fp=C8FP)
    supply_y=min(u.pin(8)[1],cc.pin(1)[1])-3.81
    p.wire(u.pin(8),(u.pin(8)[0],supply_y),(cc.pin(1)[0],supply_y),cc.pin(1))
    p.label('VBAT_SYS',(u.pin(8)[0],supply_y))
    ground_y=max(u.pin(4)[1],cc.pin(2)[1])+3.81
    common=(cc.pin(2)[0],ground_y)
    p.wire(u.pin(4),(u.pin(4)[0],ground_y),common,cc.pin(2));p.dot(common);p.ground(common)

def threshold(p,x,y,ref,unit,rail,top,bottom,out,low=False):
    """OC pulls low below threshold (low=True) or above threshold."""
    u=p.sym('Comparator:LM393',ref,x,y,'LM393BIDR',SO8,unit=unit,mpn='LM393BIDR')
    cp,cn,co=(3,2,1) if unit==1 else (5,6,7)
    xx=x-38.1;my=u.pin(cp if low else cn)[1]
    rt=R(p,xx,my-12.7,top+' 0.1%');rb=R(p,xx,my+12.7,bottom+' 0.1%')
    p.stub(rt,1,rail,3.81);p.wire(rt.pin(2),(xx,my),rb.pin(1));p.ground(rb.pin(2));p.dot((xx,my))
    p.wire((xx,my),u.pin(cp if low else cn));p.stub(u,cn if low else cp,'VREF_2V495',7.62)
    p.stub(u,co,out,7.62)
    return u

def pm_switch(p,x,y,source,target,control,ref=None,large=False):
    """Source at input, drain at output; high control enables NPN gate sink."""
    if large:
        mos=p.sym('Transistor_FET:Q_PMOS_GDS',ref,x,y,'IRF4905',TO220,angle=270,mpn='IRF4905')
        sourcepin,drainpin,gatepin=3,2,1
    else:
        mos=p.sym('EdgeMind_Power:AO4409',ref,x,y,'AO4409',SO8,mpn='AO4409')
        sourcepin,drainpin,gatepin=1,5,4
    sp=mos.pin(sourcepin);gp=mos.pin(gatepin)
    p.stub(mos,sourcepin,source,5.08);p.stub(mos,drainpin,target,10.16)
    # Gate pull-up and 12V gate/source clamp guarantee OFF with absent control power.
    xx=x-25.4;rt=R(p,xx,y-10.16,'1k' if not large else '10k')
    p.stub(rt,1,source,5.08);gate=(xx,y+10.16)
    p.wire(rt.pin(2),gate,(gp[0],gate[1]),gp);p.dot(gate)
    z=p.sym('Device:D_Zener',None,x-10.16,y+25.4,'BZT52C12','Diode_SMD:D_SOD-123',angle=270)
    p.stub(z,1,source,5.08);p.wire(z.pin(2),(xx,z.pin(2)[1]),gate)
    tr=p.sym('Transistor_BJT:MMBT3904',None,xx-2.54,y+40.64,'MMBT3904','Package_TO_SOT_SMD:SOT-23',mpn='MMBT3904')
    p.wire(gate,tr.pin(3));p.ground(tr.pin(2))
    rb=R(p,xx-22.86,y+40.64,'4.7k',a=90);p.wire(rb.pin(2),tr.pin(1));p.stub(rb,1,control,7.62)
    return mos

def buck(p,y,uref,lref,cin,cout,rboot,cboot,cvcc,rhi,rlo,cff,out):
    x=86.36
    p.box(15,y-43.18,205,107.95,out+' / 5.10V / USB-C 3A target')
    u=p.sym('EdgeMind_Power:MP2236GJ-Z',uref,x,y,'MP2236GJ-Z','Package_TO_SOT_SMD:TSOT-23-8',mpn='MP2236GJ-Z')
    left=(35.56,u.pin(2)[1]);p.wire(left,u.pin(2));p.label('VLOGIC_IN',left,180)
    for i,ref in enumerate(cin):
        xx=38.1+i*12.7;cc=C(p,xx,y+2.54,'22uF 25V X5R',ref,fp=C8FP)
        p.wire(cc.pin(1),(xx,left[1]));p.dot((xx,left[1]));p.ground(cc.pin(2))
    p.stub(u,6,'BUCK_ENABLE',7.62)
    cc=C(p,35.56,y+31.75,'1uF 25V',cvcc,fp=C8FP)
    p.wire(u.pin(7),(43.18,u.pin(7)[1]),(43.18,cc.pin(1)[1]),cc.pin(1));p.ground(cc.pin(2))
    p.wire(u.pin(1),(u.pin(1)[0],y+25.4),(u.pin(4)[0],y+25.4),u.pin(4));p.ground((x,y+25.4));p.dot((x,y+25.4))
    ll=p.sym('Device:L',lref,132.08,u.pin(3)[1],'4.7uH FXL0630-4R7-M',INDUCTOR,angle=90,mpn='FXL0630-4R7-M')
    p.wire(u.pin(3),ll.pin(1));outpt=(205.74,u.pin(3)[1]);p.wire(ll.pin(2),outpt);p.flag(out,outpt)
    rr=R(p,127,y-31.75,'10R',rboot,a=90);cb=C(p,144.78,y-20.32,'100nF 50V',cboot)
    p.wire(u.pin(5),(109.22,u.pin(5)[1]),(109.22,y-31.75),rr.pin(1));p.wire(rr.pin(2),(144.78,y-31.75),cb.pin(1))
    p.wire(cb.pin(2),(144.78,y-12.7),(116.84,y-12.7),(116.84,u.pin(3)[1]));p.dot((116.84,u.pin(3)[1]))
    for i,ref in enumerate(cout):
        xx=193.04+i*12.7;cc=C(p,xx,y+20.32,'22uF 25V X5R',ref,fp=C8FP)
        p.wire(cc.pin(1),(xx,outpt[1]));p.dot((xx,outpt[1]));p.ground(cc.pin(2))
    rt=R(p,165.1,y+5.08,'82.5k 0.1%',rhi);rb=R(p,165.1,y+30.48,'11.0k 0.1%',rlo)
    mid=(165.1,y+17.78);p.wire(rt.pin(1),(165.1,outpt[1]));p.dot((165.1,outpt[1]))
    p.wire(rt.pin(2),mid,rb.pin(1));p.wire(u.pin(8),(149.86,u.pin(8)[1]),(149.86,mid[1]),mid);p.dot(mid);p.ground(rb.pin(2))
    cc=C(p,177.8,y+5.08,'220pF C0G',cff);p.wire(cc.pin(1),(177.8,outpt[1]));p.dot((177.8,outpt[1]));p.wire(cc.pin(2),(177.8,mid[1]),mid)

def usb_port(p,y,out,icref,usbref):
    p.box(230,y-43.18,165,107.95,usbref+' / 6P power-only / fixed 5V')
    u=p.sym('EdgeMind_Power:HUSB305_02',icref,279.4,y,'HUSB305-02','Package_TO_SOT_SMD:TSOT-23-8',mpn='HUSB305-02')
    vin=(243.84,u.pin(1)[1]);p.wire(vin,u.pin(1));p.flag(out+'_PROT',vin)
    ci=C(p,243.84,y+5.08,'1uF 25V',fp=C8FP);p.wire(ci.pin(1),vin);p.dot(vin);p.ground(ci.pin(2))
    rs=R(p,251.46,y+26.67,'150k 1%');p.wire(u.pin(3),(251.46,u.pin(3)[1]),rs.pin(1));p.ground(rs.pin(2));p.ground(u.pin(2));p.nc(u,4)
    con=p.sym('Connector:USB_C_Receptacle_PowerOnly_6P',usbref,360.68,y-15.24,'USB4125-GF-A / 六针供电',USB6,angle=180,mpn='USB4125-GF-A',datasheet='https://gct.co/files/drawings/usb4125.pdf')
    p.wire(u.pin(8),con.pin('A9'));p.label(usbref+'_VBUS',(312.42,u.pin(8)[1]))
    for k,cp,xx in [(6,'A5',327.66),(5,'B5',335.28)]:
        p.wire(u.pin(k),(xx,u.pin(k)[1]),(xx,con.pin(cp)[1]),con.pin(cp))
    co=C(p,312.42,y+26.67,'4.7uF 10V X7R',fp=C8FP);p.wire(co.pin(1),(312.42,u.pin(8)[1]));p.dot((312.42,u.pin(8)[1]));p.ground(co.pin(2))
    p.ground(con.pin('A12'));p.ground(con.pin('SH'));p.stub(u,7,usbref+'_FAULT_PULSE_N',7.62)
    pull(p,347.98,y+36.83,usbref+'_FAULT_PULSE_N')
    p.text('CC attach detection + integrated VBUS switch\nISET 150k: 3.6A typ / Rp advertises 3A\nNo external Rp, USB data or PD voltage negotiation',235,y+56,0.95)

def build():
    assert hashlib.sha256((ROOT/(STEM+'.kicad_pcb')).read_bytes()).hexdigest()==EXPECTED_BOARD
    g.USED.clear();g.COMPONENTS.clear();g.COUNTS.update(R=50,C=100,U=20,J=8,D=1,Q=2,L=3,F=1,RV=0,TP=0)
    define_parts()
    root=Schematic(STEM+'.kicad_sch','EdgeMind Robot power / 2x5V + independent 3V3',1,'User')
    specs=[('01_power_input','3S input and voltage protection'),('02_usb_5v','Two MP2236 / 6P USB-C sources'),('03_aux_3v3','Independent 3V3 and source selector'),('04_motor_safety','E-stop and explicit arm latch'),('05_motor_left','Left AT8236 and current monitor'),('06_motor_right','Right AT8236 and current monitor'),('07_motor_dump','Regeneration dump'),('08_rail_protection','Low-cost output OV disconnect'),('09_control_io','FPGA control and monitor interfaces')]
    pages=[Schematic(f+'.kicad_sch',t,i+2,'User') for i,(f,t) in enumerate(specs)]
    power,usb,aux,safe,ml,mr,dump,prot,io=pages
    root.text('两路独立 5V + 默认独立 3.3V；USB-C 使用 6P 供电插座。',20,25,1.6)
    root.text('区内实线连接；跨模块标签。AT8236 使用两排排母；原 PCB 不更新。',20,35,1.3)
    root.text('三串电池经XT60接板载MINI总保险，再经防反接进入母线；单体电芯保护仍须落实。\n逻辑电源开关供两路5V降压与独立3.3V降压；动力总开关供左右电机采样电阻。\nJP1默认短接1-2，备用输入须先确认电流余量。',20,50,1.1)
    for i,page in enumerate(pages):
        xx=20+(i%3)*128;yy=89+(i//3)*57
        root.items.append(f'(sheet (at {xx} {yy}) (size 116 32) (stroke (width 0.254) (type default)) (fill (color 0 0 0 0)) (uuid {q(uid("sheet:"+page.file))}) (property "Sheetname" {q(page.title)} (at {xx} {yy-1.27} 0) {effects(0.95,justify="left")}) (property "Sheetfile" {q(page.file)} (at {xx} {yy+34} 0) {effects(0.9,justify="left")}) (instances (project {q(STEM)} (path {q("/"+ROOT_ID)} (page {q(page.index)})))))')
    root.text('Schematic R2 / PCB intentionally unchanged. Bench validation required before fabrication.\nExternal 3S cell protection required. Stepper drivers and FPGA RTL are separate system work.',20,270,1.05)

    # Raw input: 3S pack, stock XT60, board-mounted MINI fuse, reverse-source PMOS.
    p=power;p.box(15,15,380,94,'输入：三串11.1V锂聚合物电池 / 板载总保险与防反接')
    con=hdr(p,30.48,54.61,2,'CN1','XT60PW-M / 3S','Connector_AMASS:AMASS_XT60PW-M_1x02_P7.20mm_Horizontal',a=180)
    p.ground(con.pin(1));p.flag('GND',(con.pin(1)[0],con.pin(1)[1]+3.81))
    main_fuse=p.sym('Device:Fuse','F1',76.2,52.07,'10A/32V MINI总保险','Fuse:Fuseholder_Blade_Mini_Keystone_3568',angle=90,
                    mpn='0297010.J',on_board=True,
                    desc='板载MINI总保险；XT60正极经F1再进入防反接管；保险片与保险座分别采购',
                    datasheet='https://www.lcsc.com/datasheet/C55117678.pdf')
    item=parse(p.items[-1]);field_edits=[]
    for pn in children(item,'property'):
        at=child(pn,'at')
        if pn[1] in ['Reference','Value']:
            pos='(at 76.2 46.99 90)' if pn[1]=='Reference' else '(at 76.2 44.45 90)'
            field_edits.append((at.start,at.end,pos))
    p.items[-1]=apply_edits(p.items[-1],field_edits)
    p.wire(con.pin(2),main_fuse.pin(1));p.flag('BAT_POS',(50.8,52.07));p.dot((50.8,52.07))
    rev=p.sym('Transistor_FET:Q_PMOS_GDS','Q1',111.76,66.04,'IRF4905',TO220,mpn='IRF4905',angle=90)
    p.wire(main_fuse.pin(2),(96.52,main_fuse.pin(2)[1]),(96.52,rev.pin(2)[1]),rev.pin(2))
    end=(187.96,rev.pin(3)[1]);p.wire(rev.pin(3),end);p.flag('VBAT_SYS',end)
    rg=R(p,111.76,85.09,'100k');p.wire(rev.pin(1),rg.pin(1));p.ground(rg.pin(2))
    z=p.sym('Device:D_Zener',None,139.7,80.01,'BZT52C12','Diode_SMD:D_SOD-123',angle=270)
    p.wire(z.pin(1),(139.7,end[1]));p.dot((139.7,end[1]));p.wire(z.pin(2),(124.46,z.pin(2)[1]),(124.46,76.2),(111.76,76.2));p.dot((111.76,76.2))
    p.wire(end,(end[0],50.8),(269.24,50.8))
    for xx,ref,v,polar in [(205.74,'C58','470uF 35V low-ESR',True),(226.06,'C59','10uF 50V',False),(246.38,'C60','100nF 50V',False)]:cap(p,xx,66.04,'VBAT_SYS',v,ref,polar,bus=(xx,50.8))
    tv=p.sym('Device:D_TVS','D1',269.24,66.04,'SMBJ15CA','Diode_SMD:D_SMB',angle=270,mpn='SMBJ15CA');p.wire(tv.pin(1),(269.24,50.8));p.ground(tv.pin(2))
    p.text('电池：11.1V / 3600mAh / 35C；满电12.6V。\nF1板载：XT60正极之后、防反接管之前。\n保险片：集电通0297010.J，10A/32V，初值待实测。\n保险座：四孔9.92×3.40mm；与保险片分别采购。\n照片不能确认电池保护板；单体电芯保护仍须落实。\n瞬态抑制二极管不能把电压固定在17V以下。',290,56,1.0)
    p.box(15,118,177,140,'RAW-BUS reference / logic input switch')
    tl=p.sym('Reference_Voltage:TL431DBZ',None,53.34,148.59,'TL431BIDBZR','Package_TO_SOT_SMD:SOT-23',angle=90,mpn='TL431BIDBZR')
    p.wire(tl.pin(2),(tl.pin(2)[0],tl.pin(1)[1]),tl.pin(1));p.dot(tl.pin(1));p.ground(tl.pin(3))
    rb=R(p,53.34,133.35,'2.2k');p.stub(rb,1,'VBAT_SYS',3.81);p.wire(rb.pin(2),tl.pin(1));p.label('VREF_2V495',tl.pin(1))
    pm_switch(p,129.54,162.56,'VBAT_SYS','VLOGIC_IN','BUCK_ENABLE',large=True)
    p.flag('VLOGIC_IN',(172.72,233.68));cap(p,157.48,241.3,'VLOGIC_IN','100uF 25V',polar=True)
    p.box(204,118,191,140,'UV / OV WINDOW: logic 9.0-14.1V, motor 9.65-14.1V')
    u=threshold(p,260.35,152.4,None,1,'VBAT_SYS','26.1k','10.0k','BUCK_ENABLE',True)
    threshold(p,350.52,152.4,u.ref,2,'VBAT_SYS','46.4k','10.0k','BUCK_ENABLE')
    cmp_power(p,u.ref,242.57,233.68)
    pull(p,276.86,222.25,'BUCK_ENABLE','10k',to='VBAT_SYS')
    u=threshold(p,260.35,204.47,None,1,'VBAT_SYS','28.7k','10.0k','MOTOR_POWER_OK',True)
    threshold(p,350.52,204.47,u.ref,2,'VBAT_SYS','46.4k','10.0k','MOTOR_POWER_OK')
    cmp_power(p,u.ref,310.515,241.3);pull(p,360.68,240.03,'MOTOR_POWER_OK')
    p.text('OC outputs wired-AND. Motor faults clear the arm latch; voltage recovery does not re-arm.\nTotal voltage monitoring does not replace cell protection. Validate threshold/overshoot on bench.',18,273,1.05)

    # Existing two buck values / references retained where practical; integrated cheaper source IC.
    buck(usb,72.39,'U5','L1',['C1','C2','C3'],['C4','C5'],'R1','C6','C11','R2','R3','C7','+5V_FPGA')
    usb_port(usb,72.39,'+5V_FPGA','U7','USB1')
    buck(usb,185.42,'U1','L2',['C8','C9','C10'],['C12','C13'],'R6','C14','C16','R11','R12','C15','+5V_AI')
    usb_port(usb,185.42,'+5V_AI','U8','USB2')
    usb.text('两路 5V 不并联。实际负载、板端电压、线缆压降和温升需实测；USB-C 不宣告 4A。',18,280,1.0)

    # Independent fixed 3V3 buck, populated by default; physically exclusive source jumper.
    p=aux;p.box(15,15,217,129,'DEFAULT: independent 3.3V buck / initial load budget 0.5A')
    u=p.sym('Regulator_Switching:AP63203WU','U3',93.98,67.31,'AP63203WU-7','Package_TO_SOT_SMD:TSOT-23-6',mpn='AP63203WU-7')
    v=(45.72,u.pin(3)[1]);p.wire(v,u.pin(3));p.label('VLOGIC_IN',v,180)
    ci=C(p,45.72,83.82,'10uF 25V',fp=C8FP);p.wire(ci.pin(1),v);p.dot(v);p.ground(ci.pin(2))
    p.stub(u,2,'BUCK_ENABLE',7.62);p.ground(u.pin(4))
    ll=p.sym('Device:L','L3',146.05,u.pin(5)[1],'4.7uH FXL0630-4R7-M',INDUCTOR,angle=90,mpn='FXL0630-4R7-M');p.wire(u.pin(5),ll.pin(1))
    out=(207.01,ll.pin(2)[1]);p.wire(ll.pin(2),out);p.flag('+3V3_RAW',out)
    bs=C(p,124.46,87.63,'100nF 50V');p.wire(u.pin(6),(116.84,u.pin(6)[1]),(116.84,bs.pin(2)[1]),bs.pin(2));p.wire(bs.pin(1),(124.46,u.pin(5)[1]));p.dot((124.46,u.pin(5)[1]))
    for xx in [177.8,198.12]:
        co=C(p,xx,85.09,'22uF 10V X7R',fp=C8FP);p.wire(co.pin(1),(xx,out[1]));p.dot((xx,out[1]));p.ground(co.pin(2))
    p.wire(u.pin(1),(161.29,u.pin(1)[1]),(161.29,out[1]));p.dot((161.29,out[1]))
    p.text('2A IC capacity does not define connector/load budget.\nFeedback senses the buck output before protection.\n4.7uH matches the allowed 2.2-10uH range.',22,121,1.0)
    p.box(244,15,151,129,'JP1: one shunt only / source selection')
    j=hdr(p,294.64,49.53,3,'JP1','1-2 ONBOARD / 2-3 FPGA',nets=['+3V3_ONBOARD','+3V3','3V3_FPGA_IN'])
    p.flag('+3V3',(309.88,49.53));p.flag('3V3_FPGA_IN',(309.88,72.39))
    spare=hdr(p,375.92,93.98,2,None,'OPTIONAL FPGA 3V3 IN',nets=['3V3_FPGA_IN','GND'])
    p.wire(j.pin(3),(266.7,j.pin(3)[1]),(266.7,78.74),(360.68,78.74),(360.68,spare.pin(1)[1]),spare.pin(1))
    p.text('Default shunt 1-2: onboard 3V3.\n2-3 only after verifying FPGA headroom.\nNever fit two shunts. No hard paralleling.\nOnboard buck remains populated by default.',250,116,1.0)
    p.box(15,153,380,106,'FILTERED SENSOR POWER / finished 3.3V-compatible modules only')
    bead=p.sym('Device:FerriteBead',None,55.88,179.07,'220R@100MHz 1A','Inductor_SMD:L_0805_2012Metric',angle=90)
    p.stub(bead,1,'+3V3',7.62);end=(111.76,179.07);p.wire(bead.pin(2),end);p.label('+3V3_SENS',end)
    for xx,value in [(86.36,'10uF 10V X7R'),(105.41,'100nF 50V')]:cap(p,xx,194.31,'+3V3_SENS',value,bus=(xx,179.07))
    for i,name in enumerate(['IMU PWR','TOF1 PWR','TOF2 PWR','TOF3 PWR']):
        xx=185.42+(i%2)*123.19;yy=185.42+(i//2)*49.53
        h=hdr(p,xx,yy,2,None,name,'Connector_JST:JST_PH_B2B-PH-K_1x02_P2.00mm_Vertical',nets=['+3V3_SENS','GND'])
        bypass=decouple(p,xx+43.18,yy,'+3V3_SENS')
        routex=h.pin(1)[0]-2.54
        p.wire(h.pin(1),(routex,h.pin(1)[1]),(routex,yy-13.97),(bypass.pin(1)[0],yy-13.97),bypass.pin(1))
        groundbus=(bypass.pin(2)[0],yy+6.35)
        p.wire(h.pin(2),(routex,h.pin(2)[1]),(routex,yy+6.35),groundbus)
        p.dot(groundbus)
    hdr(p,104.14,238.76,2,None,'3V3 AUX OUT',TERM,nets=['+3V3','GND'])
    p.text('Default +3V3 powers encoders, current monitors and safety logic. Sensor signals connect to FPGA.\nBare sensor chips and finished modules may need different supply levels; confirm actual modules.',18,276,1.0)

    # Four physical AND gates + asynchronous-clear FF: wired local chain.
    p=safe;p.box(15,15,380,251,'MOTOR HARDWARE LATCH: power-on OFF / NC E-stop / explicit ARM rising edge')
    est=hdr(p,50.8,52.07,2,None,'ESTOP NC LOOP',TERM,nets=['+3V3','ESTOP_OK']);estpd=down(p,83.82,64.77,'ESTOP_OK')
    p.wire(est.pin(2),(73.66,est.pin(2)[1]),(73.66,estpd.pin(1)[1]),estpd.pin(1))
    down(p,40.64,93.98,'MOTOR_PERMIT');down(p,71.12,93.98,'MOTOR_ARM');pull(p,102.87,64.77,'EXT_KILL_N')
    rst=p.sym('Power_Supervisor:MCP100-300D','U13',157.48,54.61,'MCP100-300DI/TO','Package_TO_SOT_THT:TO-92_Inline',mpn='MCP100-300DI/TO')
    p.stub(rst,2,'+3V3',3.81);p.ground(rst.pin(3));p.stub(rst,1,'POR_OK',7.62);decouple(p,179.07,87.63)
    def ga(unit,x,y,an,bn):
        c=p.sym('EdgeMind_Power:74HC08','U10',x,y,'74HC08D',SO14,unit=unit,mpn='SN74HC08DR')
        aa,bb,oo={1:(1,2,3),2:(4,5,6),3:(9,10,8),4:(12,13,11)}[unit]
        if an:p.stub(c,aa,an,7.62)
        if bn:p.stub(c,bb,bn,7.62)
        return c,aa,bb,oo
    a,ai,aj,ao=ga(1,243.84,63.5,'ESTOP_OK','MOTOR_PERMIT')
    b,bi,bj,bo=ga(2,243.84,104.14,'POR_OK','EXT_KILL_N')
    c,ci,cj,co=ga(3,307.34,83.82,None,None)
    p.wire(a.pin(ao),(274.32,a.pin(ao)[1]),(274.32,c.pin(ci)[1]),c.pin(ci));p.wire(b.pin(bo),(281.94,b.pin(bo)[1]),(281.94,c.pin(cj)[1]),c.pin(cj))
    d,di,dj,do=ga(4,243.84,144.78,None,'MOTOR_POWER_OK')
    p.wire(c.pin(co),(332.74,c.pin(co)[1]),(332.74,125.73),(218.44,125.73),(218.44,d.pin(di)[1]),d.pin(di))
    ff=p.sym('74xx:74HC74','U12',320.04,180.34,'74HC74D',SO14,unit=1,mpn='SN74HC74DR')
    p.wire(d.pin(do),(294.64,d.pin(do)[1]),(294.64,ff.pin(1)[1]),ff.pin(1))
    p.stub(ff,2,'+3V3',5.08);p.stub(ff,3,'MOTOR_ARM',7.62);p.stub(ff,4,'+3V3',5.08);p.stub(ff,5,'MOTOR_ARMED',7.62);p.nc(ff,6)
    ffu=p.sym('74xx:74HC74','U12',172.72,185.42,'74HC74D',SO14,unit=2,mpn='SN74HC74DR')
    for k in [11,12,13]:p.stub(ffu,k,'GND',3.81)
    p.stub(ffu,10,'+3V3',3.81);p.nc(ffu,8);p.nc(ffu,9)
    for lib,ref,unit,x in [('EdgeMind_Power:74HC08','U10',5,53.34),('74xx:74HC74','U12',3,116.84)]:
        u=p.sym(lib,ref,x,223.52,'74HC08D' if ref=='U10' else '74HC74D',SO14,unit=unit,mpn='SN74HC08DR' if ref=='U10' else 'SN74HC74DR');p.stub(u,14,'+3V3',3.81);p.ground(u.pin(7));decouple(p,x+20.32,233.68)
    down(p,369.57,219.71,'MOTOR_ARMED','4.7k')
    p.text('Open E-stop / low PERMIT / external KILL / undervoltage / overcurrent clears immediately.\nRestore conditions then pulse ARM: no automatic restart. FPGA must drop PERMIT on watchdog/stall.\nHC08/HC74 are CMOS parts running at 3.3V. Do not substitute 74LS parts.',18,278,1.0)

    # Common motor high-side switch. Small E-stop carries only logic current.
    p=dump;p.box(15,15,170,131,'MOTOR POWER SWITCH / not a small slider in the motor path')
    pm_switch(p,106.68,58.42,'VBAT_SYS','VM_SWITCHED','MOTOR_ARMED','Q2',large=True)
    p.flag('VM_SWITCHED',(43.18,119.38));tp(p,159,119.38,'VM_SWITCHED')
    p.box(200,15,195,244,'REGEN DUMP / external chassis resistors')
    br=None
    for i,side in enumerate(['L','R']):
        yy=63.5+i*104.14
        cmp=p.sym('Comparator:LM393',br,264.16,yy,'LM393BIDR',SO8,unit=i+1,mpn='LM393BIDR');br=cmp.ref
        cp,cn,co=(3,2,1) if i==0 else (5,6,7)
        rt=R(p,224.79,yy-13.97,'51.1k 0.1%');rb=R(p,224.79,yy+11.43,'10.0k 0.1%');m=(224.79,yy-2.54)
        p.stub(rt,1,'VM_'+side,3.81);p.wire(rt.pin(2),m,rb.pin(1));p.ground(rb.pin(2));p.wire(m,cmp.pin(cp));p.dot(m);p.stub(cmp,cn,'VREF_2V495',5.08)
        gate=(302.26,yy);p.wire(cmp.pin(co),gate)
        rg=R(p,302.26,yy-17.78,'4.7k');p.stub(rg,1,'VM_'+side,3.81);p.wire(rg.pin(2),gate);p.dot(gate)
        mos=p.sym('Transistor_FET:Q_NMOS_GDS',None,332.74,yy,'IRLZ44N',TO220,mpn='IRLZ44N');p.wire(gate,mos.pin(1));p.ground(mos.pin(3))
        z=p.sym('Device:D_Zener',None,312.42,yy+20.32,'BZT52C12','Diode_SMD:D_SOD-123',angle=270);p.wire(z.pin(1),(312.42,yy));p.dot((312.42,yy));p.ground(z.pin(2))
        rh=R(p,264.16,yy+33.02,'1M',a=90);p.wire(rh.pin(1),(212.09,yy+33.02),(212.09,rb.pin(1)[1]),rb.pin(1));p.dot(rb.pin(1));p.wire(rh.pin(2),(289.56,yy+33.02),(289.56,yy),gate);p.dot((289.56,yy))
        conn=hdr(p,386.08,yy-15.24,2,None,side+' DUMP / external 3R3',TERM)
        p.stub(conn,1,'VM_'+side,5.08);p.wire(conn.pin(2),(mos.pin(2)[0],conn.pin(2)[1]),mos.pin(2))
    cmp_power(p,br,243.84,239.395)
    p.text('Dump turns ON ~15.39V; verify OFF threshold and worst-case overshoot.\nUse two 3.3ohm >=100W chassis resistors if the supply/BMS cannot absorb regen.\nCircuit operates from raw bus even when local 3V3 is absent. MOSFET cooling required.',18,277,1.0)
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

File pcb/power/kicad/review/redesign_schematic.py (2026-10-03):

"""Rebuild the schematic only; keep the board and its old libraries byte-for-byte.

Native KiCad symbols, explicit local wiring, global labels across functional pages.
All coordinates are mm. Run with the bundled Python; validate with kicad-cli.
"""
from pathlib import Path
import copy, json, re, math, uuid, hashlib
from collections import defaultdict, Counter
from kicad_tools import parse, Node, Atom, child, children, val, prop

ROOT = Path(__file__).resolve().parents[1]
STEM = 'ProPrj_power_2026-10-02'
STD = Path(r'D:\KiCad\10.0\share\kicad')
ROOT_ID = '734fd4e0-a6e1-4cb5-8348-642b7ec58253'
EXPECTED_BOARD = 'b1f0ae58f0c056b78fcf4b2b0c4fc0f67e39ae8b1f3ccb8ed98e1bcf4ab4488d'
CUSTOM = {}
LIBS = {}
USED = set()
COUNTS = {'R': 19, 'C': 69, 'U': 8, 'J': 8, 'D': 1, 'Q': 1, 'L': 3,
          'RV': 0, 'TP': 0, 'F': 0, '#PWR': 100, '#FLG': 100}
COMPONENTS = []
RFP='Resistor_SMD:R_0603_1608Metric'
CFP='Capacitor_SMD:C_0603_1608Metric'
C8FP='Capacitor_SMD:C_0805_2012Metric'
SO8='Package_SO:SOIC-8_3.9x4.9mm_P1.27mm'
SO14='Package_SO:SOIC-14_3.9x8.7mm_P1.27mm'
SOT5='Package_TO_SOT_SMD:SOT-23-5'
TO220='Package_TO_SOT_THT:TO-220-3_Vertical'
IND='Inductor_SMD:L_Coilcraft_XAL7030-472'
ELCAP='Capacitor_THT:CP_Radial_D10.0mm_P5.00mm'
TERM='TerminalBlock_Phoenix:TerminalBlock_Phoenix_MKDS-1,5-2-5.08_1x02_P5.08mm_Horizontal'
USBFP='Connector_USB:USB_C_Receptacle_GCT_USB4105-xx-A_16P_TopMnt_Horizontal'
EFUSEFP='Package_DFN_QFN:Texas_RGE0024H_VQFN-24-1EP_4x4mm_P0.5mm_EP2.7x2.7mm_ThermalVias'
USBICFP='Package_DFN_QFN:Texas_RVC0020A_WQFN-20-1EP_3x4mm_P0.5mm_EP1.6x2.6mm'

def q(v): return json.dumps(str(v), ensure_ascii=False)
def snap(v): return round(round(float(v)/1.27)*1.27,5)
def num(v): return str(round(float(v),5)).rstrip('0').rstrip('.') if '.' in str(round(float(v),5)) else str(v)
def uid(key): return str(uuid.uuid5(uuid.NAMESPACE_URL,'edgemind:schematic-r2:'+key))
def effects(size=1.0, hide=False, justify=''):
    return f'(effects (font (size {size} {size}))'+(' (hide yes)' if hide else '')+(f' (justify {justify})' if justify else '')+')'

def serialize_tree(n, source=None, level=0):
    if not isinstance(n,(list,Node)):
        if isinstance(n,Atom) and source is not None:
            raw=source[n.start:n.end]
            return q(n) if raw.startswith('"') else str(n)
        return str(n)
    if all(not isinstance(x,(list,Node)) for x in n):
        return '('+' '.join(serialize_tree(x,source,level+1) for x in n)+')'
    s='('+serialize_tree(n[0],source,level+1)
    for x in n[1:]:
        s+= ('\n'+'\t'*(level+1) if isinstance(x,(list,Node)) else ' ')+serialize_tree(x,source,level+1)
    return s+')'

def std_symbol(lib_id):
    if lib_id in CUSTOM:return CUSTOM[lib_id]
    lib,name=lib_id.split(':')
    if lib not in LIBS:
        source=(STD/'symbols'/(lib+'.kicad_sym')).read_text(encoding='utf-8')
        root=parse(source)
        LIBS[lib]=(source,{str(s[1]):s for s in children(root,'symbol')})
    source,allsyms=LIBS[lib]
    s=allsyms[name]
    parent=val(s,'extends')
    if parent:
        base=std_symbol(lib+':'+parent)
        flat=copy.deepcopy(base)
        flat[1]=q(name)
        # Serialize/parse the inherited body so quoted replacement names remain quoted.
        for node in children(flat,'symbol'):
            old=str(node[1]).strip('"')
            node[1]=q(name+old[old.rfind('_',0,old.rfind('_')):])
        for p in children(s,'property'):
            old=next((x for x in children(flat,'property') if str(x[1]).strip('"')==p[1]),None)
            if old:flat.remove(old)
            flat.append(parse(serialize_tree(p,source)))
        return parse(serialize_tree(flat, None))
    # Preserve atom quoting explicitly, including inherited symbol properties.
    return parse(serialize_tree(s,source))

def symbol_text(lib_id):
    s=std_symbol(lib_id)
    source=serialize_with_quotes(s)
    return re.sub(r'^\(symbol\s+"[^"]+"','(symbol '+q(lib_id),source,count=1)

def serialize_with_quotes(n):
    """All parsed atoms remember whether they originated as quoted tokens."""
    if not isinstance(n,(list,Node)):
        return getattr(n,'raw',None) or str(n)
    return '('+' '.join(serialize_with_quotes(x) for x in n)+')'

def capture_raw(text):
    n=parse(text)
    def walk(x):
        if isinstance(x,Atom):x.raw=text[x.start:x.end]
        elif isinstance(x,(list,Node)):
            for a in x:walk(a)
    walk(n)
    return n

# Resolve inheritance once with raw token preservation.
def resolved(lib_id):
    if lib_id in CUSTOM:return capture_raw(CUSTOM[lib_id])
    lib,name=lib_id.split(':')
    if lib not in LIBS:
        txt=(STD/'symbols'/(lib+'.kicad_sym')).read_text(encoding='utf-8')
        rt=capture_raw(txt)
        LIBS[lib]=(txt,{str(s[1]):s for s in children(rt,'symbol')})
    s=LIBS[lib][1][name]
    base=val(s,'extends')
    if not base:return capture_raw(serialize_with_quotes(s))
    flat=resolved(lib+':'+base)
    flat[1]=capture_raw('(x '+q(name)+')')[1]
    for n in children(flat,'symbol'):
        suffix=re.search(r'(_\d+_\d+)$',str(n[1])).group(1)
        n[1]=capture_raw('(x '+q(name+suffix)+')')[1]
    for p in children(s,'property'):
        old=next((p0 for p0 in children(flat,'property') if p0[1]==p[1]),None)
        if old:flat.remove(old)
        flat.append(capture_raw(serialize_with_quotes(p)))
    return flat

def cached(lib_id):
    s=resolved(lib_id)
    s[1]=capture_raw('(x '+q(lib_id)+')')[1]
    return serialize_with_quotes(s)

def custom_symbol(name,ref,pins,box=(-10.16,15.24,10.16,-15.24),description='',fp='',datasheet=''):
    x1,y1,x2,y2=box
    body=[f'(symbol {q(name)} (pin_names (offset 0.8)) (in_bom yes) (on_board yes)',
      f'(property "Reference" {q(ref)} (at 0 {y1+2.54} 0) {effects(1.27)})',
      f'(property "Value" {q(name)} (at 0 {y2-2.54} 0) {effects(1.27)})',
      f'(property "Footprint" {q(fp)} (at 0 0 0) {effects(hide=True)})',
      f'(property "Datasheet" {q(datasheet)} (at 0 0 0) {effects(hide=True)})',
      f'(property "Description" {q(description)} (at 0 0 0) {effects(hide=True)})',
      f'(symbol {q(name+"_0_1")} (rectangle (start {x1} {y1}) (end {x2} {y2}) (stroke (width 0.254) (type default)) (fill (type background))))',
      f'(symbol {q(name+"_1_1")}']
    for pin,name0,typ,x,y,a in pins:
        body.append(f'(pin {typ} line (at {x} {y} {a}) (length 5.08) (name {q(name0)} {effects(1.0)}) (number {q(pin)} {effects(1.0)}))')
    body.append('))')
    CUSTOM['EdgeMind_Power:'+name]='\n'.join(body)
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

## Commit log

2026-09-23 docs: add power budget and project references
    [power.kicad_pcb, power.kicad_sch]
2026-09-23 docs: track code and model directories
2026-09-24 hardware: update DRV8874 power schematic and PCB project
    [power.kicad_pcb, power.kicad_sch]
2026-09-30 hardware: migrate power project to EasyEDA format
    [power.kicad_pcb, power.kicad_sch]
2026-10-01 hardware: update power board design
2026-10-10 feat(fpga): add motor toggle control and PWM validation records
2026-10-10 feat(fpga): add independent 50 kHz motor duty sweep
2026-10-12 Add hardware mechanical models and four-wheel chassis references
2026-10-12 Archive Ubuntu PCB work in progress
    Add PCB routing scripts and paused design snapshots from the Ubuntu EdgeMind-Robot project.
2026-10-14 fix(fpga): stabilize motion control and document motor calibration
2026-10-15 docs(fpga): record raised-wheel tests and open-loop diagnostic plan
2026-10-15 docs(fpga): complete motor handoff and add A718 A719 diagnostics
2026-10-18 feat: add verified car control GUI and motor bench profiles
2026-10-19 docs: consolidate A723 and A740 project handoff and calibration status
    Include camera Ethernet integration, shared motion sources, tests and release evidence from the documented sessions. Clarify measured versus simulated results, provisional 234 mm turn calibration, timing failures and unresolved stop ramp behavior.
2026-10-20 feat: publish A741 motion lidar mapping and LD06 GUI handoff
    Refresh project READMEs from the LD06 serial and A741 development records; document verified paper-target tests, H20/H14 wiring, local mapping, firmware variants and pending timing acceptance. Includ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
2026-10-22 完善A741运动控制、日志和地图返程导出
2026-10-22 增加地图返程自动执行与原地转向
2026-10-22 Revert "增加地图返程自动执行与原地转向"
    This reverts commit 70773817d6e8300c16fcb61419125d0f468e6b18.
2026-10-23 标明确认可用的A741 130843基线并归档融合实验源码
2026-10-25 保存任务3/4暂停检查点、完整源码模型和验证证据
2026-10-25 补充从GitHub恢复的交接、下一位AI提示词及独立克隆验证
2026-10-27 保存2026-10-28暂停源码、完整恢复包与交接证据
2026-10-27 补充GitHub独立下载与完整交接包验证记录
2026-10-30 Refactor A745 autonomous firmware and publish current handoff
    Ship the rebuilt camera pipeline, local S1 autonomy, gyro turning and TX-only telemetry with source-bound verification and the current Flash image.
    Record successful FW74504 cold boot and forward motion, while preserving the unresolved BLOCK turning report and next diagnostic steps. Synchronize the completed project cleanup to the remote main tr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
2026-11-01 feat: EV10 per-line video link, FPGA->4A browser stream verified on hardware
    FPGA camera video now reaches the Lichee Pi 4A over UDP and renders in a
    browser. Verified on the real board after flashing bitstream
    82affbef06d0e16d9959dbfd9822c8311873014bb0cf9586e4654dcf35845a02:
    2,031,598 packets, 0 bad, 2974 frames, 28.6 fps, end1 errors/dropped 0.
    Two live frames pulled from the MJPEG stream decoded as real camera
    imagery with no row misalignment.
    Video path
    - a745_video_udp_tx: one UDP datagram per 640-px RGB565 line, carrying the
    absolute row number, so a lost packet leaves a stale row instead of
    shifting the image. IP checksum is now a compile-time localparam.
    - a745_video_capture_tx: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
2026-11-02 fix: restore TH1520 NPU video detection and document deployment
    Fix the daemon file-path protocol, bounded I/O and restart recovery, YOLOv5 box decoding and letterbox mapping. Persist NPU and UDP buffer settings, manage the web service with systemd, and document the verified 15 fps preview and 5 Hz detection workflow with hardware evidence.
2026-11-03 feat: add FW74513 local modes and bounded visual tasks
    Add local mode selection and numeric display, geometric detours, full-turn mode, and locally armed bounded ET10 intents with web target selection. Preserve the NPU video and detection overlay pipelin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
    Record the verified Flash audit, 44 RTL regressions, primitive and timing gates, and passive health evidence. Physical acceptance and measured camera/lidar calibration remain pending; automatic appro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

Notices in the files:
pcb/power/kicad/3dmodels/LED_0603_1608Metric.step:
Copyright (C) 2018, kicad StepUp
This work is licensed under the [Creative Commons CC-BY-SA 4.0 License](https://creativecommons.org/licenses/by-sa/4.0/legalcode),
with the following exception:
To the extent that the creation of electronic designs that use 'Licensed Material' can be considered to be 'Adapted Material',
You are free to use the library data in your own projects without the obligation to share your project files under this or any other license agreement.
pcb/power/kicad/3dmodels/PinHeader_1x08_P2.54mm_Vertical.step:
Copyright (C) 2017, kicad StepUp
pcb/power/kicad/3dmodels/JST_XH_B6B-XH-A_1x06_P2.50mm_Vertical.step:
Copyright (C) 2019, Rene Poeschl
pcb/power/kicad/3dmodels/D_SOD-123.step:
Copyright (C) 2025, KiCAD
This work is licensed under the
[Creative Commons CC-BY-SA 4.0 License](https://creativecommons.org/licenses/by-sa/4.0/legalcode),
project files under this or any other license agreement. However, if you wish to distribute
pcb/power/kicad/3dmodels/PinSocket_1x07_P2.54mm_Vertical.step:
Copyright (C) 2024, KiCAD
